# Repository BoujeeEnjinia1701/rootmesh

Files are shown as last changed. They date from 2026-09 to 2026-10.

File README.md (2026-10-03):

# RootMesh

     

**Area:** Agriculture · **TRL:** 3 of 9 (proof of concept on paper) · **Value-engineering target:** USD 300 (estimated cost USD 281.45) · **Difficulty:** 2 of 5

Solar-powered stakes that measure soil moisture, temperature and EC and report over LoRa to a single gateway and dashboard.

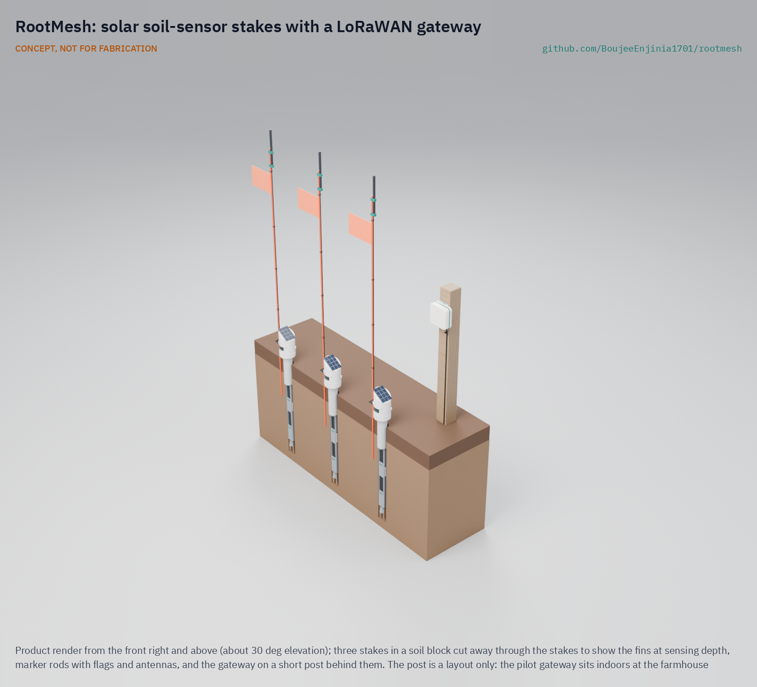
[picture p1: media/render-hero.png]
RootMesh: solar soil-sensor stakes with a LoRaWAN gateway, product render


*The gateway on a post in this render is a layout only; the pilot gateway is indoors.*

[Exploded render](media/render-exploded.png) · [Detail render](media/render-detail.png) · [Interactive 3D model](media/viewer.html) · [Concept blueprint (PDF)](media/concept-blueprint.pdf) · [General arrangement RMS-DWG-001 (PDF)](cad/drawings/RMS-DWG-001.pdf) · [Sizing calculations](docs/04-calcs/01-sizing.md) · [Prototype build plan](docs/05-build-plan.md) · [Design decisions](docs/06-design-decisions.md) · [Review note](docs/REVIEW.md)

## Concept rationale

Soil moisture only helps an irrigation decision if it is measured where the roots are, at more than one depth, and often enough to see the root zone drying between waterings. A buried stake with two capacitive probes, an EC pair and a temperature sensor answers that directly, and LoRaWAN lets one cheap gateway at the farmhouse collect a whole field without SIM cards or subscriptions. The stake sips about 2.6 mAh a day, so a palm-sized solar panel and a small LiFePO4 cell keep it running through a season with no battery changes.

RootMesh is open and garage-buildable because the growers who most need measured soil data are the ones least able to pay $150 to $600 a point for closed commercial nodes. Every part is a hobby-grade module, a hardware-store pipe or a printed piece, the known failure modes of cheap probes are designed out in the open, and a grower, extension office or school can build, repair and recalibrate the stakes without a vendor.

## Burning platform

In most regions of the world, more than 70 % of freshwater goes to agriculture ([World Bank, 2017](https://blogs.worldbank.org/en/opendata/chart-globally-70-freshwater-used-agriculture)), and irrigated land, about a fifth of cultivated area, grows about 40 % of the world's crops ([FAO, State of the World's Land and Water Resources, fast facts](https://www.fao.org/fileadmin/user_upload/newsroom/docs/en-solaw-facts_1.pdf)). Much of that water comes from aquifers that are falling: India, the largest groundwater user in the world, draws about 230 km³ a year, over a quarter of the global total, and more than 60 % of its irrigated agriculture depends on groundwater ([World Bank, 2012](https://www.worldbank.org/en/news/feature/2012/03/06/india-groundwater-critical-diminishing)).

Better timing is one of the cheapest levers. A systematic review of U.S. studies found that scheduling irrigation with soil water sensors used about 38 % less water than traditional scheduling, with similar or higher yields ([Datta and Taghvaeian 2023, *Agricultural Water Management*](https://www.sciencedirect.com/science/article/pii/S0378377423000136)). Yet field-ready wireless soil sensors still cost $150 to $600 or more per measurement point (see Problem below), which keeps them off most small farms.

## Where it could be used

### By industry

| Industry | Use |
| --- | --- |
| Vegetable and market gardening | Know when beds on drip or furrow irrigation are drying at 150 and 300 mm, and stop overwatering shallow-rooted crops |
| Orchards and vineyards | Track deep moisture and salinity through the season in a few representative blocks, and time deficit irrigation |
| Row and field crops | Place a few stakes per field or pivot to decide when to start an irrigation cycle |
| Agricultural extension and research | Deploy many low-cost points to map variation across soils and teach irrigation scheduling with real data |
| Urban and community gardens | Share one gateway across many plots and volunteers, with one dashboard for watering rotas |
| Parks, sports turf and landscaping | Skip scheduled watering when the root zone is still wet |

### By country or region

| Country or region | Why it matters there |
| --- | --- |
| India | The world's largest groundwater user; more than 60 % of irrigated agriculture depends on groundwater, and 29 % of assessed groundwater blocks were semi-critical, critical or overexploited in 2004 ([World Bank, 2012](https://www.worldbank.org/en/news/feature/2012/03/06/india-groundwater-critical-diminishing)) |
| Sub-Saharan Africa (for example Kenya) | Only about 4 % of land is irrigated, against 37 % in Asia ([IFPRI, 2010](https://www.ifpri.org/blog/irrigating-africa/)); new small-scale schemes need low-cost tools to make scarce water go further from the start |
| United States (High Plains) | Water levels in the High Plains aquifer fell by an area-weighted average of 16.5 ft (about 5.0 m) from predevelopment to 2019, a loss of about 286 million acre-feet of stored water ([USGS, 2023](https://pubs.usgs.gov/publication/sir20235143/full)) |
| Spain | Spain used about 16.7 billion m³ of irrigation water in 2010, about 42 % of the EU total ([European Parliamentary Research Service, 2019](https://www.europarl.europa.eu/RegData/etudes/BRIE/2019/644216/EPRS_BRI(2019)644216_EN.pdf)), and most of its freshwater abstraction goes to agriculture |
| Australia (Murray-Darling Basin) | The Basin accounted for 62 % of Australia's irrigation water use in 2020-21, about 4.9 million ML ([Australian Bureau of Statistics, 2022](https://www.abs.gov.au/statistics/industry/agriculture/water-use-australian-farms/latest-release)), where irrigators budget water against their entitlements |

## What sparked the idea

The idea traces back to the USDA's field guide *Estimating Soil Moisture by Feel and Appearance* (April 1998), which still underpins much irrigation scheduling advice. It asks growers to dig samples with a probe, auger or shovel in 1 ft increments down to the root depth at three or more sites per field, squeeze each one in the hand and match it to photographs, and says that with experience the method reaches about 5 % accuracy ([USDA NRCS](https://www.wcc.nrcs.usda.gov/ftpref/wntsc/waterMgt/irrigation/EstimatingSoilMoisture.pdf)). RootMesh keeps the same logic, several sites and more than one depth in the root zone, but leaves the probes in the ground and sends the readings to the farmhouse every 20 minutes, so the sampling happens without the walk and the guesswork.

## Problem

Irrigation decisions rely on guesswork without cheap, field-hardy soil sensing. Commercial wireless soil nodes cost about $150 to $600 or more per measurement point, and the cheap hobby probes corrode and drift when buried.

## Concept

Solar-powered stakes that measure soil moisture, temperature and EC and report over LoRa to a single gateway and dashboard. Each stake reads water content at 150 mm and 300 mm, bulk EC and soil temperature every 20 min, runs on a 0.5 W panel and a small LiFePO4 cell, carries its antenna at about 1 m on the flagged marker rod, and costs about $59.15 in parts. A pilot set of three stakes, an indoor US915 gateway and a steel slot tool that pre-cuts the fin path is $281.45 (indicative), USD 18.55 under the USD 300 value-engineering target.

The sizing note [RMS-CAL-001](docs/04-calcs/01-sizing.md) finds 8 of 14 requirements met on paper and 5 at risk: moisture accuracy, range through tall crops, head and cell temperature in bare hot soil, installation in firm dry soil and probe life. The parametric model is `cad/src/model.py` (STEP and STL in `cad/step` and `cad/stl`).

Full design precis: [docs/02-concept.md](docs/02-concept.md)

## Key components

- Two capacitive moisture probes (sealed, TLC555 conversion) in a printed sensor fin
- DS18B20 temperature probe
- Stainless EC electrodes with AC excitation
- LoRaWAN module (Seeed Wio-E5, STM32WLE5) with solar charger
- Sleeve dipole antenna at about 1 m on the marker rod
- 600 mAh LiFePO4 cell below grade
- 0.5 W PV panel on a printed ASA head over a PVC stake tube
- Indoor LoRaWAN gateway on The Things Network and an open-source dashboard
- Steel slot tool with a depth stop, one per set, to pre-cut the fin path before installation

The working bill of materials is in [bom/bom.csv](bom/bom.csv).

## Building the prototype

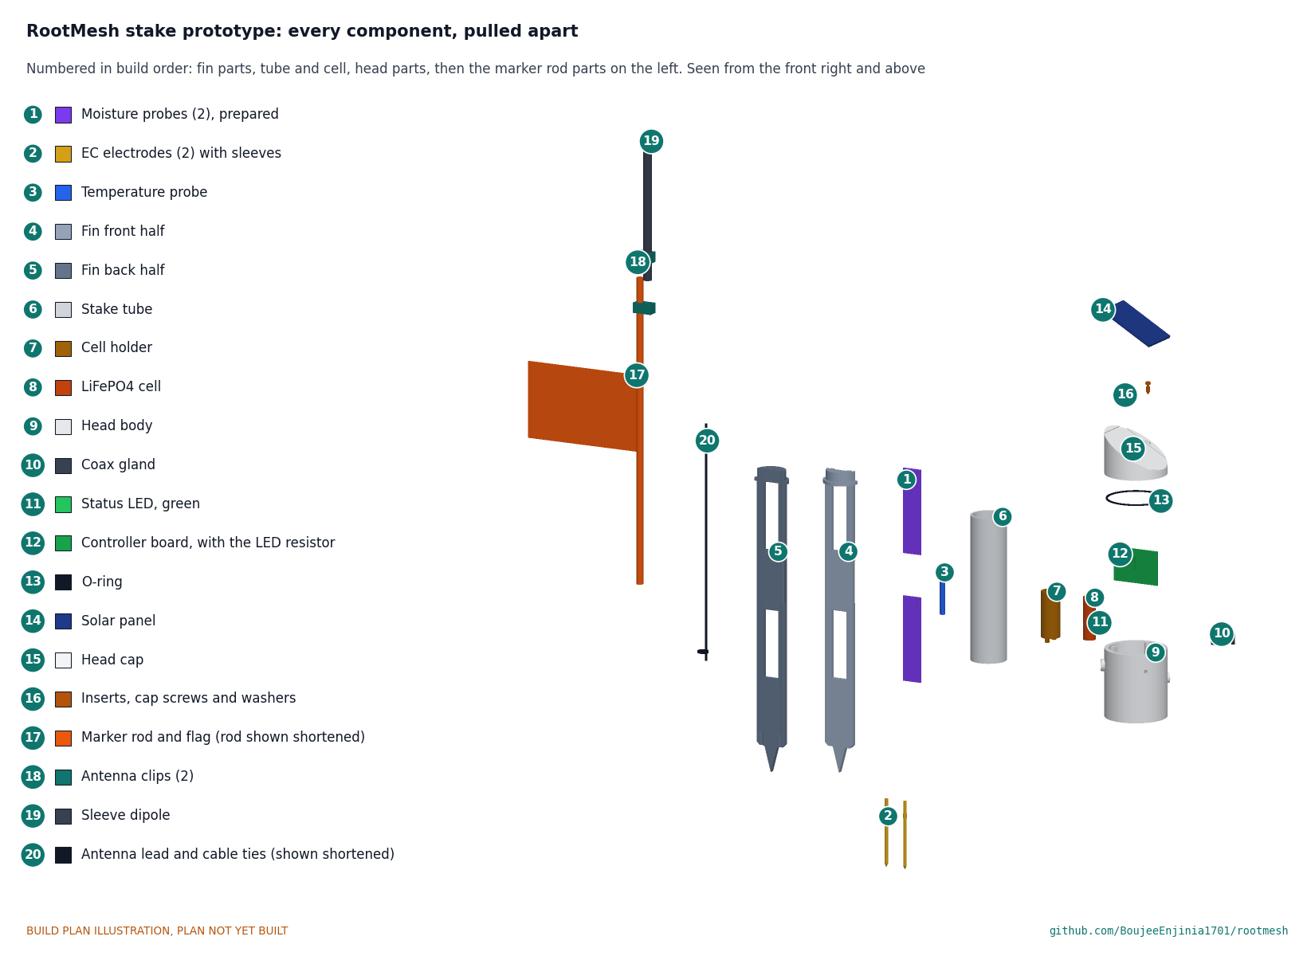
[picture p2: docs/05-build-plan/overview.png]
RootMesh stake prototype: every component pulled apart and numbered in build order


The [prototype build plan](docs/05-build-plan.md) (RMS-BLD-001) shows, in pictures, how to make each of the nineteen stake components and the slot tool and put them together in sixteen steps; nothing has been built yet. The made parts are a sensor fin printed in two glued halves, a printed head body and cap, a printed cell holder and antenna clips, a cut PVC tube, two stainless electrodes and a steel slot tool; the electronics are bought modules wired at block level. Writing the plan made the design buildable: the head now has a removable cap sealed by an O-ring so the board can go in, the fin has slots, pockets and wire channels for its sensors and a collar the tube sits on, and the cell, antenna and slot tool handle have real fixings (RMS-DDR-003, open for Amish's review). Every picture is drawn from the model, and the model checks that each part touches what it should and clears what it should not.

## Repository layout

| Folder | Contents |
| --- | --- |
| `docs/` | Problem, concept, requirements, calculations and design decisions |
| `cad/src/` | build123d Python source, the source of truth for all geometry |
| `cad/step/`, `cad/stl/` | Exported models for FreeCAD, other CAD tools and printing |
| `cad/drawings/` | 2D sketches and dimensioned drawings |
| `bom/` | Bill of materials |
| `electronics/` | KiCad schematics and PCB layouts |
| `firmware/` | Microcontroller code |
| `media/` | Renders, perspectives and photos |
| `build-log/` | Dated prototyping notes |

## Documentation

Controlled documents follow the portfolio [documentation standard](.kit/STANDARDS.md). Each carries a document ID (RMS-PRC-001 for the precis), a version and a revision history. Branded PDFs are built with `python .kit/render.py` and attached to GitHub Releases when a document is tagged, for example `RMS-PRC-001/v1.0`.

## Credits

Designed by Amish Chadha. See [CONTRIBUTORS.md](CONTRIBUTORS.md) for roles. To cite this design, use [CITATION.cff](CITATION.cff) (GitHub shows it as "Cite this repository").

AI assistance (Claude) was used to accelerate concept renders, prototype documentation and first-pass sizing calculations. Design direction and all decisions are Amish Chadha's, recorded in this repository's decision records (`docs/decisions/`).

## Licenses

- **Hardware** (CAD, drawings, BOM, electronics): [CERN-OHL-S v2](LICENSE)
- **Software** (firmware, scripts, notebooks): [MIT](LICENSE-SOFTWARE)

A project of the [Design Molecule](https://designmolecule.com) lab.

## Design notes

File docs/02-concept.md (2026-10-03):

---
doc_id: RMS-PRC-001
title: RootMesh design precis
project: RootMesh
doc_type: Design precis
version: "0.7"
status: Draft
date: '2026-10-02'
author: Amish Chadha
license: CERN-OHL-S-2.0
revisions:
- version: "0.1"
  date: '2026-09-24'
  author: Amish Chadha
  change: Initial scaffold
- version: "0.2"
  date: '2026-09-25'
  author: Amish Chadha
  change: Populate to TRL 2 (architecture, components, airtime, energy, link budget, cost, safety, media)
- version: "0.3"
  date: '2026-09-25'
  author: Amish Chadha
  change: Apply Amish's decisions (RMS-DDR-001); antenna on the marker rod; numbers checked against RMS-CAL-001; parametric model and drawing RMS-DWG-001
- version: "0.4"
  date: '2026-09-25'
  author: Amish Chadha
  change: Recommendations accepted by Amish (DDR-002)
- version: "0.5"
  date: '2026-10-01'
  author: Amish Chadha
  change: Constructable design (RMS-DDR-003) and build plan RMS-BLD-001; costs and installation figures updated; budget treated as a value-engineering target
- version: "0.6"
  date: '2026-10-02'
  author: Amish Chadha
  change: 'Decisions of 2026-10-02 (RMS-DEC-001): first users on US915 (Texas A&M AgriLife Extension as first candidate), R9 cell limit restated on condition, status light kept'
- version: "0.7"
  date: '2026-10-02'
  author: Amish Chadha
  change: "Follow-ups of 2026-10-02: US915 airtime and link budget, status LED, chosen cell and cost redone; open question on region closed"
---

# RootMesh design precis

RootMesh is a hand-installed soil sensor stake that measures volumetric water content at 150 mm and 300 mm, bulk EC and soil temperature, and reports every 20 min over LoRaWAN to one gateway at the farmhouse, from which an open dashboard shows root-zone depletion against a threshold the grower sets. The sizing note RMS-CAL-001 finds that a stake needs about 2.6 mAh a day including cell self-discharge, so a 0.5 W panel harvests about 58 times that need in the worst month and a 600 mAh LiFePO4 cell alone lasts about 186 days. With the antenna raised to about 1 m on the marker rod, the radio link has 13.5 dB of margin at 1 km. A stake costs $59.00 in parts, and a pilot set of three stakes, a gateway and a steel slot tool for installation costs $281.00. Value-engineering target: USD 300. Estimated cost of the constructable design: USD 281 (USD 19 under the target). Eight of fourteen requirements are met on paper; five are at risk: moisture accuracy (R1), range through tall crops (R5), head and cell temperature in bare, hot soil (R9), pushing the fin into firm dry soil (R10) and probe life (R14). The slot tool brings installation in moist soil within one person's strength (about 386 N); firm dry soil still needs about 1.2 kN. The design was made constructable on 2026-10-01 (RMS-DDR-003, open for Amish's review), and the prototype build plan [RMS-BLD-001](05-build-plan.md) shows how each part is made and fitted; decisions still open are in the design decisions register [RMS-DEC-001](06-design-decisions.md).

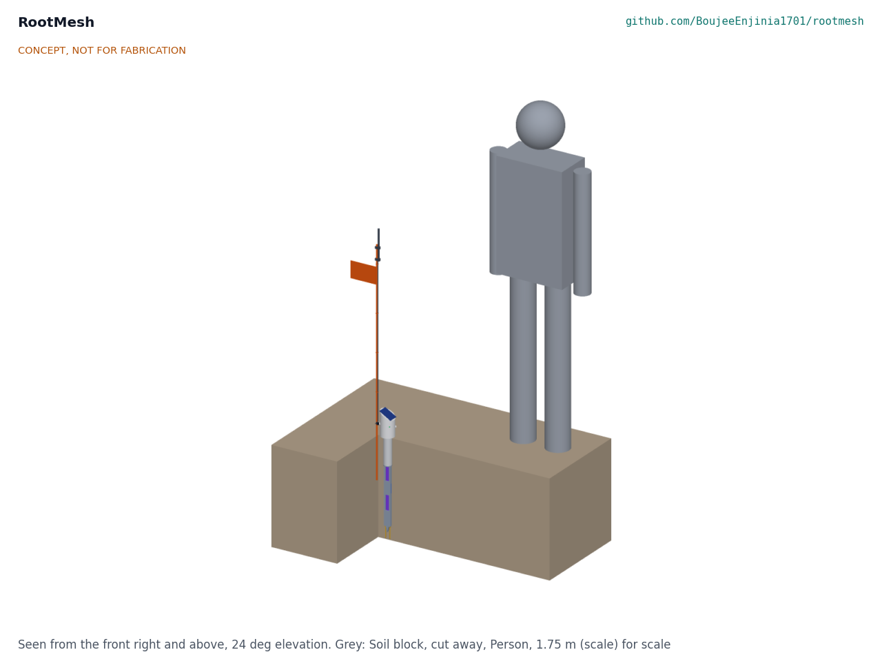
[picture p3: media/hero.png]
Hero render


*Figure 1. One RootMesh stake installed in soil, shown with the soil cut away, the marker rod with flag and antenna, and a 1.75 m person for scale.*

## How it works

1. **Sense.** Every 20 min the controller switches on the sensors for about 1 s. Two capacitive probes, held edge-on in windows of a printed fin, read water content at 150 mm and 300 mm. A DS18B20 on the fin edge reads soil temperature at about 225 mm. Two stainless electrodes below the fin tip read bulk EC with a short AC burst, so the electrodes do not polarize.
2. **Report.** The LoRaWAN module sends an 11 byte payload (24 bytes on air) at the slowest data rate the link needs, SF10 in the design case, through a sleeve dipole clipped to the top of the marker rod about 1 m above grade, then sleeps.
3. **Collect.** An indoor 8-channel gateway at the farmhouse forwards packets over Wi-Fi to The Things Network's free community server; a local server is a later option.
4. **Decide.** An open-source dashboard converts probe readings to water content with the site calibration, shows depletion between field capacity and the grower's refill point (the FAO-56 "management allowed depletion" idea; [Allen et al. 1998](https://www.fao.org/4/x0490e/x0490e00.htm)), and flags when the shallow or deep reading crosses it. Two depths show whether irrigation water has reached the lower root zone.
5. **Power.** A 0.5 W panel on the sloped head charges a 600 mAh LiFePO4 cell centered about 62 mm below grade, where the soil damps the daily temperature swing.

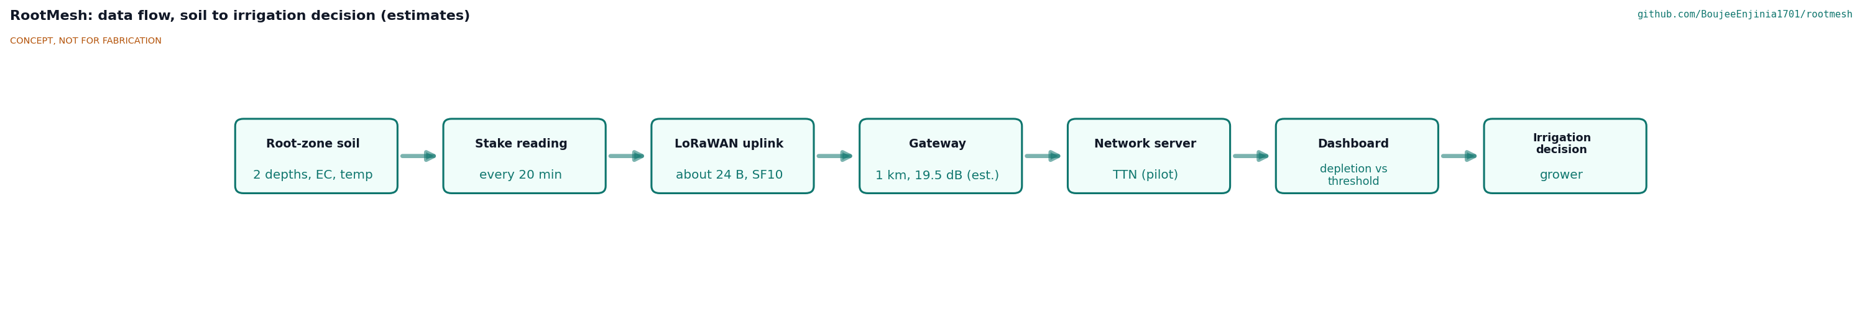
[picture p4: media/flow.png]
Data flow


*Figure 2. Data flow from the root zone to the irrigation decision. Interval, payload and range values are estimates.*

## Main components

Numbers match the exploded view (Figure 3) and `bom/bom.csv`.

| # | Component | Choice | Notes |
| --- | --- | --- | --- |
| 1 | Solar panel | 5 V, 0.5 W, about 70 x 50 mm, on a 30 degree slope | Self-cleaning slope sheds rain and dust |
| 2 | Head enclosure | Printed ASA body, 72 mm diameter, bonded over the tube, and a removable cap carrying the panel, sealed by an O-ring and two screws (RMS-DDR-003) | ASA for UV and heat; PETG softens near 70 °C |
| 3 | Controller board | STM32WLE5-class LoRaWAN module (for example Seeed Wio-E5, about $7; [Seeed Studio](https://www.seeedstudio.com/LoRa-E5-Wireless-Module-p-4745.html)) on a carrier with a LiFePO4 solar charger with NTC cut-off, a sensor power switch and the EC drive | One chip for radio and application; decided (RMS-DDR-001, D8) |
| 4 | Antenna and feed | Half-wave sleeve dipole clipped to the top of the marker rod, centered about 1,000 mm above grade, with a 1.2 m RG174 lead through a gland on the head | Decided (RMS-DDR-001, D2); a dipole because a whip on the rod has no ground plane |
| 5 | LiFePO4 cell | 14500, 3.2 V, 600 mAh (about 1.9 Wh), PTC fuse | Inside the tube below grade, in a printed holder standing on the fin spigot |
| 6 | Stake tube | 42 mm OD PVC pressure pipe, 170 mm | Carries the cable and the cell; bonded into the head and over the fin spigot |
| 7 | Sensor fin | Printed carrier 36 x 12 mm in section, 310 mm long, in two glued halves, two windows, wedge tip, collar and spigot at the top | Pushed into undisturbed soil below the 110 mm auger hole |
| 8 | Capacitive moisture probes (2) | v1.2-class boards with the NE555 replaced by a TLC555 and the edges sealed in epoxy, read as frequency | Fixes from the [Cave Pearl Project](https://thecavepearlproject.org/2020/10/27/hacking-a-capacitive-soil-moisture-sensor-for-frequency-output/) |
| 9 | EC electrodes | Two 316 stainless rods, 4 mm diameter, 24 mm apart | Two-electrode, AC excitation; cell constant set by calibration |
| 10 | Temperature probe | DS18B20 in a 6 mm stainless sheath, ±0.5 °C from -10 to 85 °C ([SparkFun](https://www.sparkfun.com/temperature-sensor-waterproof-ds18b20.html)) | Also compensates EC and moisture readings |
| 11 | Marker rod and flag | 1.2 m fiberglass rod, 8 mm, pushed 200 mm into the soil beside the stake | Visibility for machinery and people; carries the antenna |
| 12 | Seals and consumables | O-ring, IP68 glands, ePTFE vent membrane, desiccant, potting | The vent stops daily thermal pumping of about 15 kPa (RMS-CAL-001) |
| 13 | LoRaWAN gateway | Indoor 8-channel gateway with Wi-Fi (The Things Indoor Gateway class, about $79 to $90; [Seeed Studio](https://www.seeedstudio.com/The-Things-Indoor-Gateway-EU-p-4709.html)) | Not in the exploded view; The Things Network for the pilot decided (RMS-DDR-001, D3) |
| 14 | Dashboard | Open-source (for example Node-RED or Grafana) on an existing computer | Not in the exploded view |
| 15 | Slot tool | 32 x 8 mm mild steel flat bar, 650 mm, pointed, with a 20 mm bar handle through a cross hole and a printed 80 mm depth stop; one per set | Pre-cuts the fin and EC rod path; driven with a mallet, then withdrawn (RMS-DDR-002). Not in the exploded view |
| 16 | Head fixings and bonding | Two M3 heat-set inserts, two M3 cap screws with sealing washers, structural epoxy, heat-shrink sleeves, a 56 x 40 mm prototype board for the controller modules | Added for construction (RMS-DDR-003). Not in the exploded view |

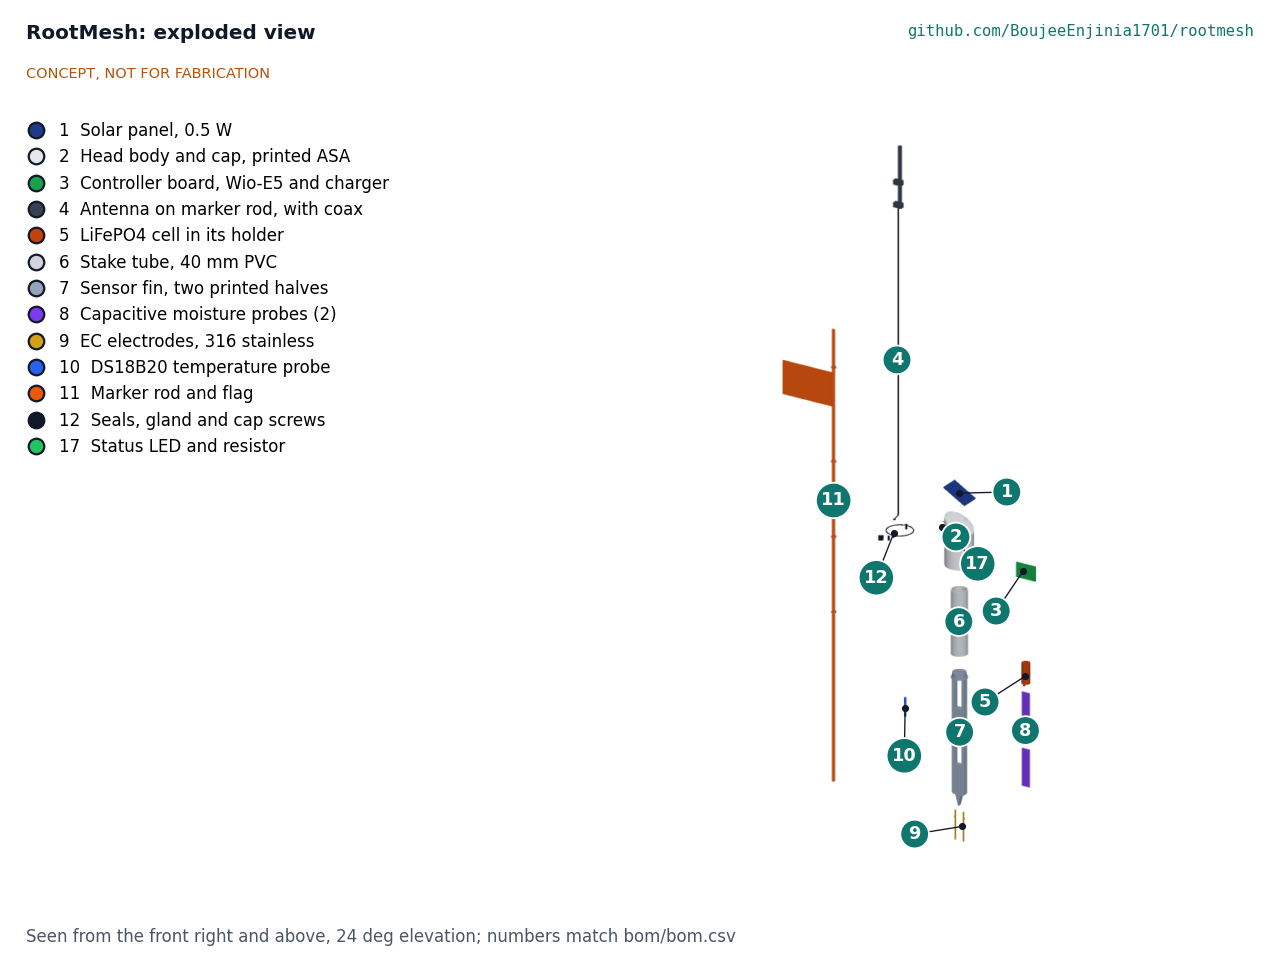
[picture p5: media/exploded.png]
Exploded view


*Figure 3. Exploded view of one stake with numbered callouts matching the BOM. The gateway and dashboard are not shown.*

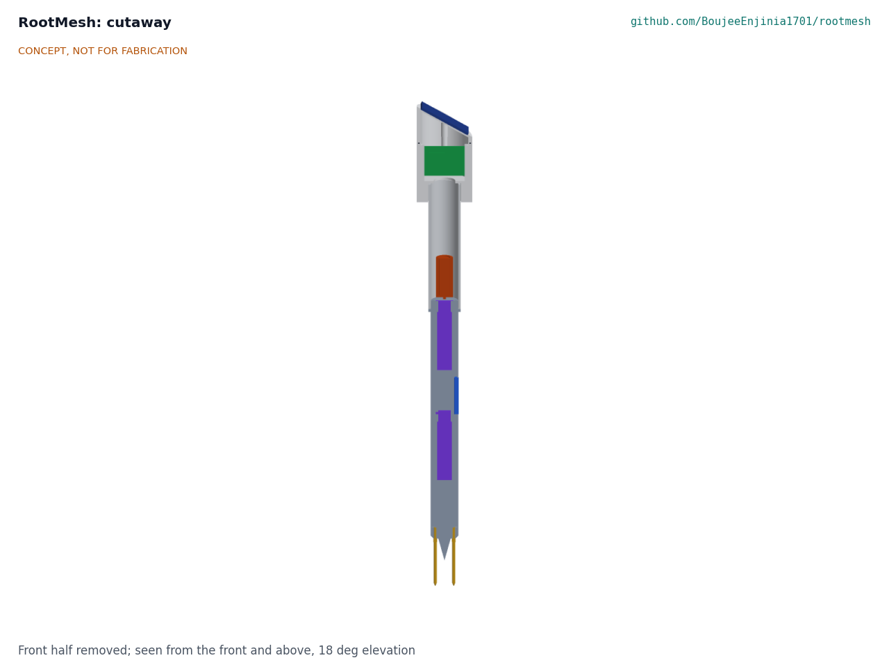
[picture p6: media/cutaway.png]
Cutaway


*Figure 4. Section through the stake: controller board in the head, cell in the tube below grade, moisture probes in the fin windows, temperature probe on the fin edge and EC electrodes below the tip. The marker rod and antenna are omitted for clarity.*

The general arrangement drawing [RMS-DWG-001](../cad/drawings/RMS-DWG-001.pdf) (Rev P2) gives the main dimensions and interfaces from the parametric model `cad/src/model.py`.

## First-order numbers

All values are estimates. They are checked in RMS-CAL-001, whose script `docs/04-calcs/sizing.py` prints every figure below.

### Airtime

Assumptions: 11 byte application payload plus 13 bytes of LoRaWAN overhead, 125 kHz bandwidth, coding rate 4/5, 8 symbol preamble, explicit header and CRC; time on air from the standard Semtech formula.

| Spreading factor | Time on air per uplink | Per day at 20 min (72 uplinks) | Per day at 15 min (96 uplinks) |
| --- | --- | --- | --- |
| SF7 | 62 ms | 4.4 s | 5.9 s |
| SF9 | 206 ms | 14.8 s | 19.8 s |
| **SF10 (design case)** | **371 ms** | **26.7 s** | **35.6 s, over the 30 s fair use limit** |
| SF12 (not allowed on US915) | 1.48 s | 106.8 s | 142.3 s |

At SF10 a 20 min interval fits The Things Network's 30 s per day fair use limit ([The Things Network](https://www.thethingsnetwork.org/docs/lorawan/duty-cycle/)); 15 min does not. With adaptive data rate, stakes close to the gateway will use SF7 to SF9 and could report every 10 to 15 min. On US915 there is no duty cycle, but each uplink may stay on a channel for at most 400 ms, so SF10 at 125 kHz (371 ms) is the slowest rate that can be used.

### Energy

Assumptions: sensors powered for 1 s at about 12 mA; microcontroller active 1.5 s at about 4 mA; transmit for the 0.371 s time on air at 120 mA (the Wio-E5 draws 111 mA at +22 dBm; [Seeed Studio](https://wiki.seeedstudio.com/LoRa-E5_STM32WLE5JC_Module/)); two receive windows 0.2 s at 6.7 mA; EC burst 20 ms at 10 mA; sleep 10 µA for the whole board including the charger; 30 % margin; cell self-discharge 3 % a month.

| Quantity | Value (RMS-CAL-001) | Basis | Requirement |
| --- | --- | --- | --- |
| Charge per report | 64.2 mAs | 12 + 6 + 44.5 + 1.3 + 0.2 + 0.2 (status LED) mAs | |
| Reports per day | 72 | Every 20 min | R4 |
| Load per day with margin | 1.98 mAh (6.3 mWh) | (1.29 active + 0.24 sleep) x 1.3 | |
| Self-discharge | 0.60 mAh per day | 3 % of 600 mAh a month | |
| **Daily need** | **2.58 mAh** | | |
| Days on the cell alone | 186 | 600 mAh x 80 % usable / 2.58 mAh | R6 (90 days) met |
| Harvest, 3 sun hours, open sky | 150 mAh per day, 58 times need | 100 mA panel current x 3 h x 50 % for tilt, dust, heat and linear charging | |
| Harvest, 1 sun hour | 50 mAh per day, 19 times need | | R6 met |
| Harvest under a canopy passing 10 % | 15 mAh per day, 5.8 times need | | |

The energy budget has large margin. That also means the panel is not strictly needed: a primary lithium cell would run a stake for years, which is how the Dragino LSE01 works ([Dragino](https://www.dragino.com/products/lora-lorawan-end-node/item/159-lse01.html)). Amish chose solar with a small rechargeable cell (RMS-DDR-001, D1) because it matches the pitch, avoids disposable cells and allows faster reporting. Charging stops below 0 °C, so in frozen ground a stake runs on its 186 days of reserve.

### Radio link

Assumptions: US915 at 915 MHz; stake radiates 20 dBm, with conducted power raised to 21.6 dBm (module maximum +22 dBm) to cover 1.6 dB of lead and connector loss; dipole taken at 0 dBi; gateway sensitivity -132 dBm at SF10 (typical SX12xx figure); 12 dB loss through the farmhouse wall and window; 10 dB allowance for crop foliage and fading; gateway at 3 m; two-ray ground reflection path loss, 40 log d - 20 log(h_t h_r), valid beyond about 115 m for these heights.

| Case | Path loss at 1 km | Loss budget available | Margin |
| --- | --- | --- | --- |
| Stake antenna 0.2 m, indoor gateway (TRL 2 layout) | 124.4 dB | 152 - 12 - 10 = 130 dB | 5.6 dB |
| **Stake antenna 1 m on the marker rod, indoor gateway (decided)** | **110.5 dB** | **130 dB** | **19.5 dB** |
| Stake antenna 0.2 m, outdoor gateway on a 6 m mast | 118.4 dB | 152 - 10 = 142 dB | 23.6 dB |

Raising the antenna to the top of the marker rod (RMS-DDR-001, D2) closes the link at 1 km on paper; at 0 dB margin it would reach about 3.1 km. The remaining risk is a crop taller than the antenna along the path: 50 m of maize or orchard can add about 13 dB and 100 m about 19 dB (Weissberger model), which leaves 0.1 dB at 100 m, so R5 stays at risk until a range walk.

### Measurement

- **Moisture.** Capacitance sensors respond to water, EC and temperature, more so at lower frequencies ([Kizito et al. 2008](https://www.sciencedirect.com/science/article/abs/pii/S0022169408000462)). Site-specific calibration cuts error to about one third of factory calibration ([Datta and Taghvaeian 2023](https://www.sciencedirect.com/science/article/pii/S0378377423000136)). The plan is a two-point field calibration (after irrigation to field capacity, and at a dry reading with a gravimetric sample) plus temperature correction from the DS18B20. Whether ±3 % VWC (R1) is reachable is unverified.
- **Air gaps.** A capacitive probe reads mostly the few millimeters of soil next to its surface, so any gap from installation reads as dry soil. The fin pushes into undisturbed soil below the auger hole to avoid this; contact quality is the largest measurement risk.
- **EC circuit.** Two 4 mm rods at 24 mm pitch with 60 mm exposed give a cell constant of about 0.13 cm⁻¹, so the electrodes read 1,315 Ω at 0.1 dS/m and 33 Ω at 4 dS/m against a 330 Ω reference. A 5 kHz square wave, sampled 10 µs after each edge, keeps polarization error under 1 %, and reading both sides of the reference resistor cancels the drive resistance (RMS-CAL-001, section D).
- **EC.** Bulk EC depends on moisture as well as salinity. Crop salinity thresholds in FAO-29 ([Ayers and Westcot 1985](https://www.fao.org/4/t0234e/t0234e00.htm)) use saturated-paste EC, so the dashboard should show EC as a trend and a pore-water estimate, not as a direct threshold. Readings are corrected to 25 °C at about 2 % per °C.

### Cost

| Group | Indicative cost | Requirement |
| --- | --- | --- |
| One stake (items 1 to 12, 16 and 17) | $59.15 | R12 ($60) met |
| Three stakes | $177.45 | |
| Gateway (item 13) | $90.00 | |
| Slot tool (item 15) | $14.00 | |
| **Pilot set** | **$281.45** | R12 ($300) met; USD 18.55 under the value-engineering target |
| Reference: Dragino SE01 node | about $151 to $170 per point ([Choovio](https://www.choovio.com/product/se01-lb-lorawan-soil-moisture-ec-sensor/)) | |

## Key design choices

Amish decided the choices below on 2026-09-25 by approving the TRL 2 recommendations (RMS-DDR-001). None is still "proposed".

- **Solar with a rechargeable LiFePO4 cell** (D1, D5): a 0.5 W panel and a 600 mAh LiFePO4 cell, rather than a primary Li-SOCl2 cell. Keeps the pitch and avoids disposable cells; adds a charger, a panel to keep clean and a cell that must not charge when frozen. LiFePO4 tolerates heat better than Li-ion and is less prone to thermal runaway.
- **Two moisture depths on one fin** (D6): 150 mm and 300 mm, to show whether water reached the lower root zone, at about $3 extra per stake.
- **Modified hobby capacitive probes** (D7): keeps the stake near $56; accuracy and life are the risks (R1, R14). A commercial reference sensor is to be borrowed for calibration later.
- **Wio-E5 (STM32WLE5) controller** (D8): one module for radio and application.
- **LoRaWAN on The Things Network for the pilot** (D3): free and simple; the fair use limit sets the 20 min interval at SF10, and a TTIG-class gateway works only with The Things Stack. A Raspberry Pi gateway with a local ChirpStack server stays a documented later option.
- **Indoor gateway, antenna on the marker rod** (D2): a sleeve dipole at about 1 m on the rod, fed by a 1.2 m lead, gives 19.5 dB margin at 1 km on US915 for $7 a stake. It adds a cable and a snag point; the rod is flexible and flagged.
- **Default interval 20 min** (D9): fits the fair use limit at SF10; faster with adaptive data rate near the gateway.
- **Budget read as a pilot set** (D4): the USD 300 value-engineering target covers three stakes and one gateway.
- **Steel slot tool for installation** (RMS-DDR-002): a pointed 32 x 8 mm steel blade, driven with a mallet down the auger hole and withdrawn, pre-cuts the fin path so the fin only widens the slot. Push force falls from 517 N to 376 N in moist loam and from 1,778 N to 1,216 N in firm dry loam (RMS-CAL-001 v0.2). Steel rather than a printed blade, because a printed blade would not survive firm soil.
- **Cell position kept at 62 mm** (RMS-DDR-002): a deeper cell was checked; in the constructable design the cell already sits as deep as fits above the fin spigot (62 mm, peak 46.8 °C in bare, hot soil), and meeting 40 °C would need about 163 mm, where the upper probe sits.

Decided by Amish on 2026-10-02 (RMS-DEC-001): the first users are a US university extension program with a research farm, on US915, with Texas A&M AgriLife Extension as the first candidate to approach; the cell limit of R9 is restated to the chosen cell's rated discharge range, provided its datasheet rates discharge to 55 °C or more, with charging still blocked above 45 °C, and otherwise a printed shade skirt is added; a green status light is kept on the head, blinking briefly after each uplink and on a magnet or button wake only, once its charge is in the energy budget. The link, airtime and power figures above are for US915 and include the status light (RMS-CAL-001 v0.5). The chosen cell is an IFR14500EC class cell, whose datasheet rates discharge from -20 to +60 °C, so no shade skirt is added.

## Safety

> **Safety:** Each stake holds a small lithium cell in a sealed enclosure buried in wet soil and exposed to sun, frost and machinery. The hazards are small but real.

- **Lithium cell.** A LiFePO4 cell of about 1.9 Wh is far less energetic than a phone battery, but a shorted or crushed cell can still overheat and vent. Fuse the cell (PTC), use a charger with an NTC input that blocks charging below 0 °C and above 45 °C, never charge a swollen or water-damaged cell, and do not leave stakes with cells in a closed hot vehicle. Plated lithium from charging below freezing can cause internal shorts later.
- **Sealed enclosure pressure.** A sealed head in sun warms from about 20 to 64 °C each day, a swing of about 15 kPa that would pump moisture past the seals. The head carries an ePTFE vent membrane and a desiccant.
- **Cell temperature.** In bare, hot soil the cell can reach about 47 °C (RMS-CAL-001). The charger's 45 °C cut-off stops charging, but check that the cell holder and fuse are rated for it, and never leave a stake in a closed vehicle.
- **Machinery and trips.** A stake struck by a tractor, mower or tiller can be thrown or can damage the implement; a low stake is a trip hazard. The flagged marker rod is part of the design, and stakes should be pulled before tillage. The antenna lead on the rod is a snag point; tape it to the rod.
- **Installation effort.** Pushing the fin into firm dry soil can take about 1.8 kN, or about 1.2 kN after the slot tool (RMS-CAL-001). Do not hammer on the head or stand on it; install after irrigation or pre-wet the hole, and cut the slot first.
- **Slot tool.** A pointed steel blade struck with a mallet: wear eye protection and gloves, keep feet clear of the point, keep the depth-stop collar fitted, and store the tool with a tip cover.
- **Sharp parts.** The fin tip and stainless electrodes are pointed; handle and store with tip covers, and keep away from children and livestock.
- **Chemicals and electrical.** Epoxy potting and conformal coating need gloves and ventilation. The stake runs at 3.2 V and carries no shock hazard; the gateway plugs into mains indoors through its own certified USB supply.
- **Data is not advice.** Readings inform a grower's decision. A failed or badly calibrated stake can read wet when the soil is dry, so growers should keep checking the crop, especially while the system is new.

## Open questions after TRL 3

- First users and region for co-design: decided on 2026-10-02, a US university extension program on US915, first candidate Texas A&M AgriLife Extension. The link budget and airtime for US915 are still to be worked.
- Can the moisture calibration reach ±3 % VWC in two soils (R1)? Needs a gravimetric calibration at TRL 4.
- Does the link hold through tall crops at 1 km (R5)? Needs a range walk at TRL 4.
- A deeper cell cannot keep the cell under 40 °C in bare, hot soil (R9). Decided on 2026-10-02: the cell limit is restated to the chosen cell's rated discharge range if its datasheet rates discharge to 55 °C or more; otherwise the soil around the head is shaded with a printed skirt.
- The slot tool brings moist soil within one person's strength on paper, but not firm dry soil (R10). A timed installation trial is TRL 4 work, on hold.
- Which edge seal lets the hobby probes last 12 months buried (R14)?

Concept media: [blueprint sheet](../media/concept-blueprint.pdf), [interactive 3D model](../media/viewer.html).

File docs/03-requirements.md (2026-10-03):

---
doc_id: RMS-REQ-001
title: RootMesh requirements
project: RootMesh
doc_type: Requirements
version: "0.7"
status: Draft
date: '2026-10-02'
author: Amish Chadha
license: CERN-OHL-S-2.0
revisions:
- version: "0.1"
  date: '2026-09-24'
  author: Amish Chadha
  change: Initial scaffold
- version: "0.2"
  date: '2026-09-25'
  author: Amish Chadha
  change: First measurable requirements for TRL 2, with concept status for each
- version: "0.3"
  date: '2026-09-25'
  author: Amish Chadha
  change: Apply Amish's decisions (RMS-DDR-001); redefine R4, R5, R11, R12 and R13; status from RMS-CAL-001
- version: "0.4"
  date: '2026-09-25'
  author: Amish Chadha
  change: Recommendations accepted by Amish (DDR-002)
- version: "0.5"
  date: '2026-10-01'
  author: Amish Chadha
  change: Figures for the constructable design (RMS-DDR-003, RMS-CAL-001 v0.3); budget treated as a value-engineering target; no status changed
- version: "0.6"
  date: '2026-10-02'
  author: Amish Chadha
  change: 'R9 cell limit restated to the chosen cell''s rated discharge range (55 °C or more), charging blocked above 45 °C, as decided by Amish on 2026-10-02'
- version: "0.7"
  date: '2026-10-02'
  author: Amish Chadha
  change: "Follow-ups of 2026-10-02: R5 margin on US915, R9 cell chosen, R12 cost with the status LED; no status changed"
---

# RootMesh requirements

These requirements reflect Amish's decisions of 2026-09-25 (RMS-DDR-001 and RMS-DDR-002) and the constructable design of RMS-DDR-003 and are checked by calculation in RMS-CAL-001. Targets are not yet validated with growers and will be revised after user input (see RMS-PRB-001; first users are still open). Nothing has been built or measured, so "met" means met on paper, by calculation or by a datasheet.

**Reference case:** one stake in a loam field, sensing at 150 and 300 mm, reporting every 20 min at SF10 to an indoor gateway about 1 km away, with the antenna at about 1 m on the marker rod, in a region with 3 peak sun hours per day in the worst month.

*Table 1. Requirements and TRL 3 status (RMS-CAL-001, Table 6).*

| ID | Requirement | Target | Verification (TRL 3 or later) | Status at TRL 3 |
| --- | --- | --- | --- | --- |
| R1 | Measure volumetric water content at two root-zone depths | 150 mm and 300 mm below grade (±25 mm); 5 to 50 % VWC; ±3 % VWC after a site-specific calibration | Model geometry; later gravimetric calibration in two soils | **At risk**: depths met by the model; accuracy depends on probe contact and calibration |
| R2 | Measure root-zone soil temperature | ±0.5 °C from -10 to 60 °C at about 225 mm depth | DS18B20 datasheet; model geometry | Met (datasheet; 225 mm in the model) |
| R3 | Measure bulk soil electrical conductivity | 0 to 4 dS/m; ±10 % or ±0.1 dS/m, whichever is larger, after calibration in standard solutions; reported at 25 °C | Circuit calculation; later bench test in KCl solutions and soil | Met on paper: circuit error under 2 % (RMS-CAL-001, D) |
| R4 | Report often enough for daily irrigation decisions | Every 20 min by default (RMS-DDR-001, D9); adjustable from 10 to 60 min where the spreading factor keeps uplink airtime at 30 s or less per day; the default fits at SF10 | Airtime calculation | Met: 26.7 s per day at SF10 and 20 min; 15 min needs SF9 or faster |
| R5 | Reach the gateway | 90 % or more of uplinks received at 1 km from an indoor gateway, with the stake antenna at about 1 m on the marker rod (RMS-DDR-001, D2), open field with a mature crop | Link budget; later field range walk | **At risk**: 19.5 dB margin at 1 km on US915 (20 dBm radiated), but a crop taller than the antenna can take 13 to 19 dB, which leaves 0.1 dB at 100 m of crop |
| R6 | Run on sun alone | Energy-neutral with 1 peak sun hour per day on the panel; 90 days or more of reporting with no harvest at all | Energy budget | Met: 19 times daily need at 1 sun hour; 186 days on the cell alone |
| R7 | Safe cell and charging | LiFePO4 chemistry, 2 Wh or less per stake; charging blocked below 0 °C and above 45 °C cell temperature; cell fused | Design review; charger datasheet | Met by design (1.92 Wh, NTC cut-off, PTC fuse) |
| R8 | Keep water out | Head IP67; buried section IP68 at 0.5 m for a growing season; UV-stable exposed parts | Design review; later immersion and spray test | Not verifiable at TRL 3; vent membrane added against 15 kPa daily thermal pumping |
| R9 | Operate across field temperatures | -10 to 60 °C at the head; at the cell, the chosen cell's rated discharge range, which its datasheet must rate to 55 °C or more, with charging blocked above 45 °C (restated from -5 to 40 °C by Amish, 2026-10-02; if the cell is not rated to 55 °C, a printed shade skirt round the head is added) | Component datasheets; thermal estimate | **At risk**: head about 64 °C and cell up to about 47 °C in bare, hot soil (parts rated 85 °C); inside the chosen IFR14500EC class cell's datasheet discharge range of -20 to +60 °C (RMS-DEC-001; no shade skirt needed); the head stays over its 60 °C |
| R10 | Install and remove by hand | One person with a 50 mm hand auger and the slot tool (RMS-DDR-002) installs a stake in 15 min or less, with sensing depths repeatable to ±25 mm; removal by hand in 5 min or less | Push-force estimate; later timed trial | **At risk**: with the slot tool about 386 N in moist loam (within one person's 500 N), about 1.2 kN in firm dry loam (without the tool 526 N and 1.8 kN); auger hole 110 mm deep (RMS-DDR-003) |
| R11 | Survive field operations | Rigid head 300 mm or less above grade; anything higher, including the antenna (RMS-DDR-001, D2), carried on the flexible marker rod; high-visibility marker 1 m or more above grade | Model check | Met: head 171 mm; rod top 1,000 mm; antenna 914 to 1,086 mm on the rod |
| R12 | Affordable | One stake $60 or less in parts; pilot set of three stakes, one gateway and the installation slot tool $300 or less, which is how the $300 value-engineering target is read (RMS-DDR-001, D4) | Priced BOM (`bom/bom.csv`) | Met: $59.15 per stake; $281.45 per pilot set including the slot tool, USD 18.55 under the value-engineering target (indicative, RMS-DDR-003 and the status LED of 2026-10-02) |
| R13 | Grower owns the data | Data readable without a paid subscription; CSV export; open dashboard. The pilot uses The Things Network community server (RMS-DDR-001, D3) | Design review | Met by design; a fully local server with a different gateway stays a later option |
| R14 | Last in the ground | Probes and electrodes last 2 growing seasons (about 12 months buried) without replacement | Materials review; later soak test | **At risk**: hobby probes corrode quickly unless sealed |

Summary: 8 met, 5 at risk (R1, R5, R9, R10, R14), 1 not verifiable at TRL 3 (R8), none not met.

## Assumptions

- Soil water content, not soil water potential, is the quantity measured. Converting it to plant-available water needs field capacity and wilting point for the soil, set during calibration (FAO-56 method).
- EC is measured as bulk soil EC. Pore-water or saturated-paste EC, which crop salinity thresholds use, differ and need a moisture-dependent conversion.
- LoRaWAN uplink payload of 11 bytes (two moisture counts, EC, temperature, cell voltage, status), 24 bytes on air with LoRaWAN overhead.
- SF10 at 125 kHz is the design case because it is the slowest uplink data rate allowed in the US915 plan and a reasonable margin case in EU868.
- The Things Network fair use policy (30 s of uplink airtime per node per day) applies when the community network is used.
- Worst-month solar resource of 3 peak sun hours on the panel before shading and dust losses.

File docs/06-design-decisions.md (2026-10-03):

---
doc_id: RMS-DEC-001
title: RootMesh design decisions register
project: RootMesh
doc_type: Design decisions register
version: "0.3"
status: Draft
date: '2026-10-02'
author: Amish Chadha
license: CERN-OHL-S-2.0
revisions:
  - version: "0.1"
    date: '2026-10-01'
    author: Amish Chadha
    change: Register opened with the open decisions from the review note and decision records, the design for construction (RMS-DDR-003), items to confirm when parts are bought, and the value-engineering summary
  - version: "0.2"
    date: '2026-10-02'
    author: Amish Chadha
    change: Amish approved the recommendations for open items 1 to 7 on 2026-10-02 (RMS-DDR-003 accepted, fin printed on a 300 mm class printer, head bonded, R9 cell limit restated on condition, Texas A&M AgriLife Extension on US915 as first candidate, status light, gateway indoors); moved to decisions made
  - version: "0.3"
    date: '2026-10-02'
    author: Amish Chadha
    change: "Follow-ups of 2026-10-02 carried out; cost restated with the status LED (line 17)"
---

# RootMesh design decisions register

Every design decision still to be made, and every decision made, in one place. Each decision is argued in full in its decision record under `docs/decisions/` or in the review note (`docs/REVIEW.md`); this register is the index Amish works from. The build plan (`docs/05-build-plan.md`) describes the design as it stands and does not list open decisions.

## Open decisions

None. All open decisions were decided on 2026-10-02.

## To confirm when parts are bought

| # | What to confirm | Why it matters | Source |
| --- | --- | --- | --- |
| 1 | The moisture probe boards are 23 mm wide and 98 to 100 mm long, with their parts on one face within 16 x 3 mm at the top end | The fin's slots and electronics pockets are sized for them | RMS-DDR-003, P4 |
| 2 | The temperature probe's sheath is 6 mm across and about 50 mm long, and its inner wires fit a 3.5 x 5 mm channel with the jacket stripped | The fin's bore and channel are sized for it | RMS-DDR-003, P5 |
| 3 | The 14500 cell with its fuse and leads fits a 15 mm bore, 51 mm deep | The cell holder is sized for it | RMS-DDR-003, P7 |
| 4 | The PVC pipe is 42 mm outside and 36 mm inside diameter | The head socket (43 mm) and fin spigot (35.4 mm) leave glue gaps of about 0.5 and 0.3 mm | RMS-DDR-003, P3 |
| 5 | A 64 x 2 mm O-ring, an M8 gland for 2 to 4 mm cable with its locknut, and short M3 heat-set inserts for a 4.6 mm hole are available | The cap groove, gland boss and insert bosses are sized for them | RMS-DDR-003, P1 and P8 |
| 6 | The solar panel is 70 x 50 mm or smaller, with its lead near the centre of its back | The cap recess is 71 x 51 mm with a lead hole at its centre | RMS-DDR-003, P1 |
| 7 | The charger's temperature window is 0 to 45 °C | R7 and safety stops S3 to S5 depend on it | RMS-CAL-001, B6 |
| 8 | The shaft collars fit 20 mm bar | The slot tool handle depends on them | RMS-DDR-003, P11 |

## Value engineering

Value-engineering target: USD 300. Estimated cost of the constructable design: USD 281.45 (USD 18.55 under the target), for the pilot set of three stakes, one gateway and one slot tool; USD 59.15 per stake against R12's USD 60. The target is a hypothetical control target, not a limit. Main cost drivers and savings worth trying:

- The largest lines are the gateway (USD 90, about a third of the set), the controller board (USD 15 a stake, USD 45 for three), the antenna and feed (USD 7 a stake) and the seals (USD 5 a stake).
- Making the design constructable added USD 3.50 a stake (the two-part head, the fin halves, and the inserts, screws, epoxy and prototype board of line 16) and USD 4 on the slot tool (shaft collars and thumb screw); the set rose from USD 266.50 to USD 281, and to USD 281.45 on 2026-10-02 with the status LED and resistor of line 17 (USD 0.15 a stake).
- Savings worth trying: one gateway serves a whole farm, so the per-stake cost falls quickly in larger sets; the controller board's price should fall once the carrier board is designed at TRL 4; one slot tool serves every stake on a farm; O-rings, glands and inserts are much cheaper bought by the hundred.

## Decisions made

| Date | Decision | Decided by | Record |
| --- | --- | --- | --- |
| 2026-09-25 | TRL 2 review items D1 to D9: solar with a LiFePO4 cell, antenna at 1 m on the marker rod, The Things Network with an indoor gateway, the budget read as a pilot set, LiFePO4 chemistry, two moisture depths, modified hobby probes, Wio-E5 controller, 20 min interval | Amish: "proceed with all of your recommendations across all batches. Make sure we don't proceed to TRL 4 on any of them." | RMS-DDR-001 |
| 2026-09-25 | Slot tool for firm soil; deeper cell checked and kept at 62 mm; pilot set includes the slot tool; field calibration note decided but on hold | Amish: "i accept all your recommendations, go with them across all repos." | RMS-DDR-002, A1 to A4 |
| 2026-09-30 | Build plan format approved for all repos; open decisions go in this register, not in the build plan; the design is made physically buildable as the pictures are drawn | Amish: "this is the correct build plan ... this is a good quality document format. Extend this across all the other repos"; "If you are realising that the design cannot be built as per concept - fix the design assumptions to match and be physically feasible as you draw the illustrations." | RMS-BLD-001, RMS-DDR-003 |
| 2026-10-01 | The budget is a value-engineering target, not a limit; `budget_usd` stays USD 300 | Amish: "the budgets are a hypothethical control target to ensure we are thinking along a value engineering lens. its ok to ensure wording reflects that the hypothesis budget was x - the real cost being accrued is y" | This register, Value engineering |
| 2026-10-02 | Design for construction accepted, P1 to P11, as recorded (two-part head with O-ring and screws, which also settles the separate solar cap of the 2026-09-26 review; board guides; fin in two glued halves with collar and spigot; flush temperature probe; wedge tip and one-piece electrodes; cell holder; gland and vent moved; antenna clips; slot tool handle and stop fixings) | Amish: "i approve your recommendations for all 555 open decisions." | RMS-DDR-003, P1 to P11 |
| 2026-10-02 | Fin print size: option (a), each 355 mm fin half is printed on a 300 mm class printer or through a print service | Amish: "i approve your recommendations for all 555 open decisions." | RMS-DDR-003, A1 |
| 2026-10-02 | Head joint: option (a) for the prototype, the head is bonded to the tube; revisited after the TRL 4 soak test | Amish: "i approve your recommendations for all 555 open decisions." | RMS-DDR-003, A2 |
| 2026-10-02 | Cell temperature in bare, hot soil: option (B), R9's cell limit restated to the chosen cell's rated discharge range, with charging still blocked above 45 °C, provided its datasheet rates discharge to 55 °C or more; if it does not, the printed shade skirt round the head (option A) is added | Amish: "i approve your recommendations for all 555 open decisions." | RMS-DDR-002, P1 |
| 2026-10-02 | First users and region: a US university extension program with a research farm, on US915; first candidate to approach Texas A&M AgriLife Extension | Amish: "i approve your recommendations for all 555 open decisions." | RMS-DDR-001, O1 |
| 2026-10-02 | Status light: keep a green LED on the head, blinking briefly after each uplink and on a magnet or button wake only, once its charge is added to the energy budget (RMS-CAL-001) | Amish: "i approve your recommendations for all 555 open decisions." | REVIEW.md, 2026-09-26, item 2 |
| 2026-10-02 | Gateway in the hero render: the pilot gateway stays indoors as decided; the post in the hero render is a layout only, and its caption says so | Amish: "i approve your recommendations for all 555 open decisions." | REVIEW.md, 2026-09-26, item 3 |

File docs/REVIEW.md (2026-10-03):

# Review note: RootMesh

## Session 2026-09-25: /populate to a strong TRL 2 (overnight batch run)

### What was done

- `docs/01-problem.md` (RMS-PRB-001 v0.2): problem with sourced facts (water use, sensor adoption, sensor prices, hobby probe failure modes, calibration error), users, operating environment, constraints, out of scope, prior work with links, open questions. No co-design checklist existed, so none was kept or added.
- `docs/03-requirements.md` (RMS-REQ-001 v0.2): 14 measurable requirements (R1 to R14) with targets, verification and concept status, plus assumptions.
- `docs/02-concept.md` (RMS-PRC-001 v0.2): how it works, 14 numbered components, airtime, energy, radio link budget, measurement notes, cost, design choices, safety, open questions.
- `cad/src/concept_media.py`: massing model of one stake (panel, ASA head, controller board, antenna, LiFePO4 cell, PVC tube, sensor fin, two probes, EC electrodes, temperature probe, marker rod, seals). Hero context: soil block cut away around the stake and a 1.75 m person standing on the soil.
- `media/`: hero, blueprint sheet (PNG, PDF, SVG), cutaway, exploded view with BOM callouts 1 to 12, data flow diagram, `model.glb` and `viewer.html`.
- `bom/bom.csv`: 14 lines for a pilot set (three stakes and one gateway), rows 1 to 12 numbered to match the exploded view; `bom/bom-notes.md` rewritten.
- `README.md`: hero image and links line added; problem, concept and key components updated to match.
- `docs/pdf/`: branded PDFs of the three controlled documents.
- `project.yaml` unchanged. The pitch and problem still match the numbers.

### Key results (estimates, to be checked at TRL 3)

| Quantity | Estimate | Requirement |
| --- | --- | --- |
| Time on air, 24 byte uplink at SF10 | about 0.37 s | |
| Airtime per day at 20 min, SF10 | about 27 s (30 s limit) | R4 met |
| Airtime per day at 15 min, SF10 | about 36 s | 15 min not possible at SF10 |
| Daily use with 30 % margin | about 2.0 mAh (6.4 mWh) | |
| Life on the 600 mAh cell alone | about 240 days | R6 met |
| Solar harvest to use ratio | about 70 times (open sky), about 7 times (dense canopy) | R6 met |
| Link margin at 1 km, indoor gateway, antenna 0.2 m | about 0 dB | **R5 not met** |
| Same with antenna at 1 m on marker rod | about 14 dB | R5 met on paper |
| Cost per stake | about $52 | R12 met |
| Pilot set (three stakes and gateway) | about $246 against $300 | R12 met |

Requirements not met or at risk:

- **R5 (range) not met** with the modeled design (whip on the head, indoor gateway): about 0 dB margin at 1 km.
- **R4 partly:** met at the 20 min default, but a 15 min interval at SF10 breaks The Things Network's 30 s per day limit.
- **R1 (moisture ±3 % VWC) at risk:** depends on soil contact and a site calibration, both unverified.
- **R14 (12 months buried) at risk:** hobby probes corrode unless sealed well.
- **R13 partly:** the TTIG-class gateway works only with The Things Stack, so fully local data needs a different gateway.
- R3, R8 and R10 are unverified.

### Proposed, awaiting Amish

1. **Power and pitch.** A: 0.5 W solar panel with a LiFePO4 cell (keeps the "solar-powered" pitch). B: primary Li-SOCl2 cell, no panel (simpler, multi-year life, changes the pitch). Recommendation: A.
2. **Range fix.** A: antenna on the marker rod at 1 m (about $4 a stake). B: outdoor gateway on a mast (about $150 to $250 more, over budget). C: accept about 500 m range. Recommendation: A. The model and BOM still show the whip on the head.
3. **Network.** The Things Network with a TTIG-class gateway for the pilot, or a Raspberry Pi gateway with local ChirpStack (about $60 to $100 more). Recommendation: TTN for the pilot.
4. **Budget reading.** The $300 taken as a pilot set of three stakes and one gateway. `budget_usd` unchanged.
5. LiFePO4 rather than Li-ion chemistry.
6. Two moisture depths (150 mm and 300 mm) rather than one.
7. Modified hobby capacitive probes rather than commercial FDR probes.
8. STM32WLE5-class module (Seeed Wio-E5) as the controller.
9. Default reporting interval of 20 min.
10. First users and region (market garden, orchard, research farm or extension program).

### Safety concerns

- LiFePO4 cell (about 1.9 Wh) in sun and frost: fused, charging blocked below 0 °C and above 45 °C, cell kept below grade.
- Machinery strikes and trip hazard: flagged marker rod; pull stakes before tillage.
- Pointed fin tip and electrodes: tip covers in storage.
- Epoxy and conformal coating: gloves and ventilation.
- Bad readings can mislead irrigation: the documents say readings inform, not replace, the grower's judgment.

### Problems and notes

- Several parts are small next to a 1.75 m person, so the hero shows a soil block cut away around the stake to make the buried sensors visible. The DS18B20 (10) and cell (5) are small in the exploded view but visible below their callouts.
- The LoRa module and carrier board are one BOM line (3) so the callout marks a visible part.
- Transmit current (about 120 mA) is an order-of-magnitude figure for an SX126x-class radio; confirm from the chosen module's datasheet at TRL 3.
- The link budget uses a simple two-ray model and typical sensitivity; range must be walked at TRL 4.
- The legacy `cad/src/model.py` placeholder is untouched (TRL 3 work).

### Suggestions (not done, outside this session's scope)

- A calibration note (CAL) for the two-point field calibration and EC cell constant at TRL 3.
- A simple printed tool to cut a slot for the fin in heavy soils.

### Recommended next step

Review this note and the media, then decide items 1 and 2. If approved, run `/advance-trl3` to check the energy, airtime, link and EC circuit numbers by calculation and produce the parametric model and drawing sheet.

## Session 2026-09-25: TRL 3

Amish approved all TRL 2 recommendations on 2026-09-25 ("proceed with all of your recommendations across all batches. Make sure we don't proceed to TRL 4 on any of them."). This session advanced RootMesh to TRL 3 and stopped there.

### What was done

- `docs/decisions/0001-trl2-review-decisions.md` (RMS-DDR-001 v0.1): the nine decided items (D1 to D9) and the one open item (O1).
- `docs/04-calcs/01-sizing.md` (RMS-CAL-001 v0.1) and `docs/04-calcs/sizing.py`: airtime, energy, radio link, EC circuit, sensing geometry, thermal and sealing, installation force and cost, with a results table for R1 to R14. The script imports the model's parameters, reads the BOM and `project.yaml`, and prints every number the note quotes.
- `cad/src/model.py`: parametric build123d model of one installed stake (head, panel, controller, tube, cell, fin, probes, EC rods, temperature probe, seals, marker rod, flag, antenna and lead). Exports `cad/step/` and `cad/stl/`: `rootmesh-stake-assembly`, `head-enclosure`, `sensor-fin`, `stake-tube`.
- `cad/src/sheets.py` and `cad/drawings/RMS-DWG-001.svg`, `.pdf`, `.png`: general arrangement at Rev P1, orthographic views at 1:5, installed elevation at 1:20, isometric, main dimensions and interfaces. The concept sheet keeps RMS-DWG-010, so RMS-DWG-001 was free. The sheet carries "CONCEPT, NOT FOR FABRICATION" and "PRELIMINARY, NOT FOR FABRICATION".
- `bom/bom.csv` and `bom/bom-notes.md`: every line priced with a supplier or supplier type; antenna and feed now $7.00 (on the marker rod), seals $5.00 (vent added). Pilot set $256.50 against $300.
- `cad/src/concept_media.py` now builds the media from `model.py`; all media refreshed (hero, blueprint, cutaway, exploded, flow, `model.glb`, `viewer.html`) and checked by eye. Temporary `media/_views*` folders removed.
- RMS-PRB-001, RMS-PRC-001 and RMS-REQ-001 revised to v0.3; `README.md` and `project.yaml` (trl 3, trl_target 3, evidence list) updated. Pitch, problem and `budget_usd` unchanged.
- Model fix found on the way: the TRL 2 massing model tilted the panel away from the equator; the parametric model faces it toward +X as the precis says.

### Requirements (RMS-CAL-001, Table 6)

Counts: 0 not met, 5 at risk, 1 not verifiable at TRL 3, 8 met.

| ID | Status | Key number |
| --- | --- | --- |
| R1 moisture | At risk | Depths 150 and 300 mm met by the model; ±3 % VWC unverifiable on paper |
| R5 range | At risk | 13.5 dB margin at 1 km with the antenna at 1 m; 50 to 100 m of tall crop takes 13 to 19 dB |
| R9 temperature | At risk | Head about 64 °C at 45 °C air (limit 60 °C; parts rated 85 °C); cell up to about 47 °C in bare hot soil (limit 40 °C) |
| R10 installation | At risk | Push force about 520 N in moist loam, about 1.8 kN in firm dry loam; one person gives about 500 N |
| R14 probe life | At risk | 12 months buried depends on the epoxy edge seal |
| R8 sealing | Not verifiable at TRL 3 | Sealed head would see about 15 kPa daily thermal pumping; ePTFE vent added |
| R2, R3, R4, R6, R7, R11, R12, R13 | Met | 26.7 s/day airtime at SF10; 2.58 mAh/day need, 186 days dark, 19 times need at 1 sun hour; 1.92 Wh cell; EC circuit error under 2 %; head 171 mm; $55.50 per stake |

Corrections to TRL 2 figures: days on the cell fell from about 240 to 186 (self-discharge), the harvest ratio from about 70 to 58 times, and the pilot set rose from about $246 to $256.50.

### Decisions recorded (RMS-DDR-001)

Decided by Amish, 2026-09-25: go with recommendation.

- D1 solar panel with rechargeable cell (pitch kept); D2 antenna on the marker rod at about 1 m; D3 The Things Network with a TTIG-class gateway for the pilot; D4 $300 read as a pilot set of three stakes and a gateway (`budget_usd` unchanged, written into R12); D5 LiFePO4; D6 two moisture depths; D7 modified hobby capacitive probes; D8 Wio-E5 (STM32WLE5); D9 20 min default interval.
- Requirement changes that follow: R4 redefined around the 20 min default, R5 for the antenna on the rod, R11 so that only the rigid head is held to 300 mm, R12 and R13 name the decisions. No target was relaxed.
- The portfolio SwapCell decisions do not apply; RootMesh uses no SwapCell pack.

### Still awaiting Amish

- O1: first users and region for co-design (market garden, orchard, research farm or extension program), which also sets EU868 or US915. No recommendation was made; co-design partners are to be picked per area later.

### Safety concerns

- LiFePO4 cell (1.92 Wh): may reach about 47 °C in bare, hot soil; the charger's 45 °C cut-off only stops charging. Fused (PTC), charging blocked below 0 °C.
- Sealed head: about 15 kPa daily pressure swing without a vent; ePTFE vent added.
- Machinery strikes and trips: flagged marker rod; the antenna lead on the rod is a snag point; pull stakes before tillage.
- Installation: up to about 1.8 kN in firm soil; do not hammer on or stand on the head.
- Pointed fin tip and electrodes; epoxy and coating fumes; readings inform, not replace, the grower's judgment.

### Citations and other notes

- The TRL 2 note listed no unchecked citations. The module currents that note flagged were checked against the Seeed Studio Wio-E5 module page (111 mA at +22 dBm, 6.7 mA receive, 2.1 µA sleep) and cited in RMS-CAL-001.
- No TRL 4 material exists in the repo (`electronics/` and `firmware/` are empty; `build-log/` holds only its README). None was created.

### Recommended next step

TRL 4 is on hold by Amish's instruction; this repo stops at TRL 3. Useful paper work that stays within TRL 3: decide O1 (first users and region), then consider design responses to the at-risk items, such as a deeper cell position or soil shade for R9 and a thin slot tool for R10, as a TRL 3 revision.

For the record only, TRL 4 would need: a lab test report (TST, `environment: lab`) covering the EC circuit in KCl standards, gravimetric moisture calibration in two soils, a soak and immersion test of the sealed head and probes, and a measured energy budget on a built stake; build log entries; and later a field range walk through tall crops. None of this is to start until Amish lifts the TRL cap.

## Session 2026-09-25: recommendations accepted

Amish wrote on 2026-09-25, in chat: "i accept all your recommendations, go with them across all repos." This session applied that instruction inside this repo only, at TRL 3, and recorded it in `docs/decisions/0002-recommendations-accepted.md` (RMS-DDR-002 v0.1).

### Decisions applied and what changed

The TRL 2 items D1 to D9 were already decided in RMS-DDR-001 and are unchanged. Newly decided (Decided by Amish, 2026-09-25: go with recommendation):

| # | Item | Change | Before | After |
| --- | --- | --- | --- | --- |
| A1 | Slot tool for firm soil (TRL 2 suggestion) | Steel slot tool, 32 x 8 mm blade pointed at 485 mm, T-handle, printed depth stop; `build_slot_tool()` in `cad/src/model.py`, `cad/step/slot-tool.step` and `cad/stl/slot-tool.stl`; BOM line 15 | Push force 517 N moist, 1,778 N firm dry | 376 N moist, 1,216 N firm dry |
| A2 | Deeper cell for R9 (TRL 3 recommended next step) | Checked by calculation (RMS-CAL-001 v0.2, [F4]); no geometry change | Cell peak 46.8 °C at 62 mm | Deepest fit about 65 mm gives 46.5 °C; 40 °C needs about 163 mm, where the upper probe sits; cell stays at 62 mm |
| A3 | Pilot set includes the slot tool | R12 restated; `budget_usd` unchanged at $300 | Pilot set $256.50, headroom $43.50 | $266.50, headroom $33.50 |
| A4 | Field calibration note (TRL 2 suggestion) | Decided but on hold: the field calibration needs gravimetric samples and KCl standards (TRL 4) | | |

Documents changed: RMS-PRC-001 v0.3 to v0.4, RMS-REQ-001 v0.3 to v0.4, RMS-CAL-001 v0.1 to v0.2 (script `docs/04-calcs/sizing.py` updated and re-run), RMS-DWG-001 Rev P1 to P2 (slot tool note), `bom/bom.csv` and `bom/bom-notes.md`, `README.md`, `project.yaml` (evidence list only). Media and all PDFs regenerated; STEP and STL re-exported. RMS-PRB-001 is unchanged (it did not attribute the idea to a brainstorm or review).

### Requirement status (RMS-CAL-001 v0.2)

Counts unchanged: 0 not met, 5 at risk, 1 not verifiable at TRL 3, 8 met.

- At risk: R1 (moisture accuracy), R5 (range through tall crops), R9 (head about 64 °C; cell about 47 °C in bare, hot soil), R10 (now 376 N in moist loam, within one person's 500 N, but 1,216 N in firm dry loam), R14 (probe life).
- Not verifiable at TRL 3: R8 (sealing).
- Met: R2, R3, R4, R6, R7, R11, R12 ($55.50 per stake, $266.50 pilot set), R13.

### Still awaiting Amish

- O1: first users and region for co-design (sets EU868 or US915). No recommendation was made.
- P1 (new, from the A2 check): respond to the cell temperature in bare, hot soil by (A) a printed shade skirt around the head or (B) restating the R9 cell limit to the chosen cell's rated discharge and storage range, with charging still blocked above 45 °C. Recommendation: B, after confirming the cell's rated range.

### Cross-repo actions

None. No RootMesh recommendation needs another repo to change.

### Other changes

- `README.md`: added "Concept rationale", "Burning platform", "Where it could be used" and "What sparked the idea" before "Problem", with cited figures (World Bank, FAO, USGS, ABS, European Parliamentary Research Service, IFPRI, Datta and Taghvaeian 2023). The inspiration point is the USDA NRCS guide *Estimating Soil Moisture by Feel and Appearance* (April 1998).
- All generated files regenerated so they carry designmolecule.com.

### Safety

The slot tool adds a pointed steel blade struck with a mallet: eye protection, gloves, feet clear of the point, collar fitted, tip cover in storage (RMS-PRC-001 v0.4, Safety). The earlier concerns (cell temperature, installation force, machinery strikes, sealed-head pressure) stand.

### TRL 4

TRL 4 remains on hold by Amish's instruction. No hardware, test, trial, PCB or firmware work was started. The field calibration (A4), a timed installation trial with the slot tool and any build of it wait for Amish to lift the cap.

## Session 2026-09-26: product appearance model and photoreal renders

Amish chose RootMesh for the first batch of product renders on 2026-09-26. This session added an appearance model for photoreal renders; the massing model, BOM, calculations and drawing are unchanged.

### What was done

- `cad/src/product_model.py` (new): `product_parts()` returns 85 parts (18 shell, 7 internal, 60 context) with colour, material class, BOM line, group and explode offset, plus `TITLE` and three `RENDER_VIEWS` (hero, exploded, detail). It imports `PARAMS` and `derived()` from `cad/src/model.py`, and every main dimension and interface (tube, socket, head radius and height, 30 degree slope, panel size, board and cell positions, fin, windows, sensing depths, EC pitch, temperature probe depth, marker rod, flag and antenna height) is taken from there. Appearance detail added:
  - head with filleted top and bottom edges, a grip-rib band, a dark nameplate with a teal line, a green status light behind a clear lens, a gland nut and dome on the coax boss and a white ePTFE vent disc;
  - a solar cap split from the head on a parting line parallel to the slope, carrying the panel (cell grid and busbars) and two cap screws;
  - controller board with the LoRaWAN module shield, charger IC and connectors; O-ring; LiFePO4 cell with terminals in its holder;
  - stake tube with eased ends; sensor fin with filleted edges, teal depth marks below each window, the capacitive probes with an epoxy edge seal, a stainless temperature sheath and stainless EC electrodes;
  - marker rod with a fabric flag, cable ties along the coax, and the sleeve dipole with its clip;
  - context: a two-layer soil block cut away on the plane through the stakes, two more stakes, and the gateway on a short timber post with bracket, status light and USB lead.
- `README.md`: the hero image is now `media/render-hero.png`, with a link to `media/render-exploded.png`. The render files are produced separately.
- Matplotlib self-check previews (not committed) were used to check that the hero, exploded and detail views read clearly.

### Where the appearance model differs from model.py

1. **Solar cap as a separate part.** `model.py` has a one-piece printed head. The appearance model splits a 10 mm cap off the top on a parting line and shows it exploded with the panel. Proposed, awaiting Amish. Options: (A) keep the one-piece head and read the line as cosmetic; (B) adopt a separate cap with the panel bonded to it, sealed to the head by a second O-ring. Recommendation: B, because the panel and board could then be serviced without pulling the stake; size the second seal in the next design step.
2. **Status light.** A green status LED behind a clear lens on the front of the head is not in the BOM or the energy budget. Proposed, awaiting Amish. Recommendation: keep it, driven as a brief blink after each uplink and on a magnet or button wake only, and add its charge to the RMS-CAL-001 energy budget before adopting it.
3. **Gateway outdoors on a post.** `model.py` and RMS-DDR-001 D3 keep the TTIG-class gateway indoors at the farmhouse; the hero shows it on a short timber post behind the stakes so one frame explains the system. Proposed, awaiting Amish. Recommendation: keep the pilot gateway indoors as decided and treat the post as a render layout only; the render note says so.
4. **Stake spacing.** The hero places three stakes 330 mm apart on one section plane. In the field they stand in different parts of a block or field. Render layout only; no change proposed.
5. **Colours.** The massing colours are replaced with product colours: white head and cap, light grey tube, mid-grey fin, black probes, stainless electrodes and temperature sheath, orange rod and flag. Appearance only; no change proposed.

### TRL

This is an appearance model only, for renders. It adds no tolerances, fabrication detail, PCB layout or test work. `trl` stays 3 and TRL 4 remains on hold.

## Session 2026-09-27: kit 1.5.0 and image quality

- Kit 1.5.0 synced: STANDARDS v1.5 (sections 12 to 15: product renders, storefront images and image quality, public release, authorship and signing), `.kit/cards.py`, `.kit/image_qc.py`, `.kit/release_gate.py`, issue templates, and the `/render-product` and `/release` commands. `CLAUDE.md` now matches `.kit/CLAUDE.md`.
- Every `media/render-*.png` recaptioned from its original render with the new layout: the title, concept label and repository sit in a band above the render and the view note in a band below it, each line wrapped to the image width, so no text overlaps other text or the render or runs off the image. `media/card.png` and `media/social-preview.png` regenerated with the same rules.
- `python .kit/image_qc.py` and `python .kit/release_gate.py` pass. trl stays 3.

## Session 2026-10-01: kit 1.7.0, design for construction and prototype build plan

Amish approved the build plan format on 2026-09-30 and asked for it across all repos, with open decisions kept in a separate register; on 2026-10-01 he asked that budgets be treated as value-engineering targets. This session applied both to RootMesh at TRL 3. Nothing was built or tested.

### What was done

- Kit 1.7.0 installed (`.kit/`, `.claude/commands/`); `CLAUDE.md` matches `.kit/CLAUDE.md`.
- `cad/src/model.py` rewritten as a constructable model: `build_components()` gives every part, `build_parts()` groups them by BOM line for the concept media, `slot_tool_components()` gives the slot tool, and `python cad/src/model.py --check` runs 331 constructability checks (no overlaps, every joint touches, board and cell holder pass their openings, cap screws clear the panel, gland nut clears the board, fin halves fit a 300 mm print bed). All pass. STEP and STL exported for the assembly and every made part (`cad/step`, `cad/stl`).
- `docs/decisions/0003-design-for-construction.md` (RMS-DDR-003 v0.1, Draft): the design changes below, made under Amish's 2026-09-30 instruction to make the design physically buildable; open for his review.
- `cad/src/build_plan_media.py` (new): overview, slot tool overview, ten making sketches RMS-DWG-101 to 110, a fin inside-face layout, eleven joint close-ups, sixteen assembly step pictures and a wiring diagram, all drawn from the model.
- `docs/05-build-plan.md` (RMS-BLD-001 v0.1) and `docs/06-design-decisions.md` (RMS-DEC-001 v0.1), new.
- `bom/bom.csv` and `bom/bom-notes.md`: lines 2, 4, 5, 7, 11, 12 and 15 updated; line 16 (head fixings and bonding) added.
- `docs/04-calcs/sizing.py` and RMS-CAL-001 v0.3, RMS-REQ-001 v0.5, RMS-PRC-001 v0.5: re-run and updated for the constructable design; budget wording changed to a value-engineering target.
- RMS-DWG-001 Rev P4; concept media (`media/hero.png`, `exploded.png`, `cutaway.png`, `flow.png`, `concept-blueprint.*`, `model.glb`, `viewer.html`) regenerated.
- `project.yaml`: `design_state: constructable`; RMS-DDR-003, the build plan, the register and the media script added to `trl_evidence`; `budget_usd` unchanged at 300.
- `README.md`: value-engineering line, build plan and register links, a "Building the prototype" section with the overview picture (placed before "Repository layout", since this README has no "Safety" section), updated costs.

### Design changes made for construction (RMS-DDR-003)

1. Head split into a printed body bonded over the tube and a removable cap carrying the panel, sealed by a 64 x 2 mm face O-ring and held by two M3 screws with sealing washers into heat-set inserts; body wall 5 mm (was 3 mm); the one-piece head could not take the board and its O-ring sealed nothing.
2. Board held in two printed guide slots.
3. Fin topped by a 42 mm collar and a 35.4 mm spigot bonded in the tube; the tube moved up 14 mm (still 170 mm long) so the upper probe stays centred at 150 mm; auger hole 110 mm deep (was 120 mm).
4. Fin printed in two glued halves with probe slots, electronics pockets, wire channels, a temperature probe bore and electrode grooves; windows 19 mm wide (was 28 mm).
5. Temperature probe recessed into the fin edge (0.4 mm proud; it stood 7 mm out and would have been torn off).
6. Round tip replaced by a wedge between the electrodes; each electrode one 80 mm rod (15 mm held, 5 mm sleeved, 60 mm bare, as before).
7. Printed cell holder standing on the spigot, cell centre still 62 mm deep.
8. Coax gland moved to 100 mm above grade, turned toward the front, clear of the board.
9. Vent moved to the back right, clear of the screw bosses.
10. Two printed antenna clips and four cable ties in place of an overlapping block and a free-hanging lead.
11. Slot tool handle through a cross hole with two shaft collars; depth stop clamped by an M5 thumb screw; blade 650 mm as the BOM says.

### Key results

- Requirement status unchanged: 8 met, 5 at risk (R1, R5, R9, R10, R14), 1 not verifiable at TRL 3 (R8), none not met.
- R10: with the slot tool 386 N in moist loam (was 376 N) and 1,245 N in firm dry loam (was 1,216 N); the fin now starts 10 mm deeper.
- R9: the deepest cell centre that fits is now 62 mm (46.8 °C), where the cell already sits.
- Cost: USD 59.00 a stake (R12's USD 60 met by USD 1); pilot set USD 281.00. Value-engineering target: USD 300. Estimated cost of the constructable design: USD 281 (USD 19 under the target).

### Proposed, awaiting Amish

All open decisions are in `docs/06-design-decisions.md`: accept RMS-DDR-003; fin print size (A1); head bonded to the tube (A2); the R9 response (P1); first users and region (O1); the status light; the gateway in the hero render.

### Stale images

The design changed visibly (two-part head with a parting line and screw heads, collar on the fin, narrower windows, wedge tip, antenna clips). `media/render-hero.png`, `render-exploded.png`, `render-detail.png`, `media/card.png`, `media/social-preview.png` and the appearance model `cad/src/product_model.py` still show the concept and need regenerating on Amish's Mac.

### Safety

The build plan carries eight safety stops (cell, charging, slot tool, radio, field). The slot tool is a pointed steel blade struck with a mallet; grinding steel and epoxy work are added workshop hazards. The safety case is otherwise unchanged.

### Recommended next step

Review RMS-DDR-003 and the register. TRL 4 (building to this plan) stays on hold until Amish lifts the cap.

## Session 2026-10-02: open decisions decided

Amish, 2026-10-02: "i approve your recommendations for all 555 open decisions." This approves the recommendation written for each open decision in the design decisions register (RMS-DEC-001 v0.1). trl stays 3; no build or test work was done, and the model, BOM quantities and prices, and pictures are unchanged.

### Decisions recorded

Seven decisions, all moved to Decisions made in RMS-DEC-001, dated 2026-10-02:

1. RMS-DDR-003 accepted: design for construction P1 to P11, as recorded (including the separate solar cap).
2. Fin print size: option (a), a 300 mm class printer or a print service.
3. Head joint: option (a), bonded to the tube for the prototype; revisited after the TRL 4 soak test.
4. Cell temperature (R9): option (B), the cell limit restated to the chosen cell's rated discharge range, with charging still blocked above 45 °C, provided its datasheet rates discharge to 55 °C or more; otherwise the printed shade skirt (A) is added.
5. First users and region: a US university extension program with a research farm, on US915; Texas A&M AgriLife Extension is the first candidate to approach.
6. Status light: a green LED on the head, blinking briefly after each uplink and on a magnet or button wake only, once its charge is in the energy budget.
7. Gateway: indoors as decided; the post in the hero render is a layout only, and its caption says so.

### Documents changed

- `docs/06-design-decisions.md` (RMS-DEC-001 v0.2): open decisions moved to Decisions made; the note on the separate solar cap folded into decision 1.
- `docs/decisions/0003-design-for-construction.md` (RMS-DDR-003 v0.2, status Draft): accepted, with A1 and A2 accepted as recommended.
- `docs/decisions/0001-trl2-review-decisions.md` (RMS-DDR-001 v0.2): O1 recorded as decided.
- `docs/decisions/0002-recommendations-accepted.md` (RMS-DDR-002 v0.2): O1 and P1 recorded as decided.
- `docs/03-requirements.md` (RMS-REQ-001 v0.6): R9 cell limit restated (still at risk for the head).
- `docs/04-calcs/01-sizing.md` (RMS-CAL-001 v0.4): R9 target in the requirement table; no number re-run.
- `docs/02-concept.md` (RMS-PRC-001 v0.6): decisions on first users, US915, R9 and the status light; open questions answered.
- `docs/01-problem.md` (RMS-PRB-001 v0.4): first users and region.
- `README.md`: caption under the hero render (the post is a layout only).

### Follow-up actions to carry approved decisions into the design

1. Decision 4 (calculations and BOM): choose the cell, confirm from its datasheet that discharge is rated to 55 °C or more, and record it in the BOM notes; if it is not, add the printed shade skirt to the model, BOM, drawings and build plan pictures.
2. Decision 5 (calculations): redo the link budget, airtime and fair use figures of RMS-CAL-001 and RMS-PRC-001 for US915 (915 MHz, US power limits, 400 ms dwell time).
3. Decision 5 (model and BOM): cut the sleeve dipole for 915 MHz and specify the US915 gateway and antenna in the BOM (build plan section 3.12 and safety stop S7).
4. Decision 6 (calculations, model, BOM): add the LED's charge to the energy budget in RMS-CAL-001, then add the lens hole in the head body, the LED and its resistor to the model and BOM.
5. Decision 7 (pictures): put the "layout only" note in the hero render's own caption when the renders are next made (`.kit/photo_caption.py`).
6. Decision 1 (pictures): update `cad/src/product_model.py` to the constructable head, fin and antenna clip and re-render the photoreal renders, card and social preview on Amish's Mac.

### Points found in the review

- R9 also sets 60 °C at the head, which the head exceeds (about 64 °C at 45 °C air); neither option in decision 4 addresses it, and it was not an open item. R9 stays at risk for the head.
- Charging is blocked above 45 °C cell temperature, which in bare hot soil falls in the sunniest afternoon hours; the energy budget should show the solar charge still covers the load.

## Session 2026-10-02: approved follow-ups carried out

Amish, 2026-10-02: every follow-up action from the open-decision sign-off is approved and to be completed. trl stays 3; no build or test work was done. `budget_usd` is unchanged.

### Approved follow-ups carried out

1. Decision 4, cell: done. The cell is an IFR14500EC class LiFePO4 cell (600 mAh, 3.2 V). Its datasheet ([Simpower IFR14500EC](https://www.simpower.co.nz/wp-content/uploads/2021/11/IFR14500EC.pdf)) rates discharge from -20 to +60 °C and charge from 0 to +60 °C, so the 55 °C condition is met and the printed shade skirt is not added. BOM line 5 and the build plan record it; the charger still blocks charging above 45 °C. The datasheet is for the class, not for a purchased lot: check the supplier's own sheet before buying.
2. Decision 5, US915 calculations: done. RMS-CAL-001 v0.5 and RMS-PRC-001 v0.7 redo airtime (400 ms dwell limit, SF10 takes 371 ms), the link budget (915 MHz, 20 dBm radiated, margin at 1 km 19.5 dB) and the energy budget.
3. Decision 5, dipole and gateway: done. The model's dipole is 164 mm (was 172 mm); BOM line 4 is a 915 MHz dipole and line 13 the US915 gateway; build plan section 3.12 and stop S7 say so.
4. Decision 6, status LED: done. Charge added to the energy budget (RMS-CAL-001 [B1b]: 2.14 mA, 0.21 mAs per report, 3.2 mAs a day of wake blinks, five wakes a day assumed), then a 5.2 mm lens hole, the LED and its 560 Ω resistor added to the model (388 checks pass, 0 failures), BOM line 17 ($0.15 a stake), the build plan and the wiring picture.
5. Decision 7, hero caption: done in the render scene. The hero view's note now says the post is a layout only and the pilot gateway sits indoors; it travels in `rootmesh__jobs.json` to `.kit/photo_caption.py`.
6. Decision 1, appearance model and renders: the appearance model `cad/src/product_model.py` is updated to the constructable head (lens hole, gland and vent at the model positions), the fin collar and spigot, the cell holder, the two antenna clips, the cable tie heights and the 915 MHz dipole, with the dimensions read from `cad/src/model.py`. Render scenes exported to `/home/claude/renders/rootmesh` (hero, exploded, detail). Not done: the photoreal renders, `media/card.png` and `media/social-preview.png`, which are made on Amish's Mac next.

### Results

- Model: 388 constructability checks, 0 failures; STEP and STL regenerated.
- BOM: line 17 added; lines 3, 4, 5 and 13 reworded for US915 and the chosen cell; no other line changed. One stake $59.15, pilot set $281.45. Value-engineering target: USD 300. Estimated cost of the constructable design: USD 281.45 (USD 18.55 under the target). Mass is not tracked in the bill of materials.
- Requirement status changes: none (8 met, 5 at risk: R1, R5, R9, R10, R14; 1 not verifiable at TRL 3: R8). R5 margin rose to 19.5 dB but tall crops still take it down to 0.1 dB at 100 m of crop, so it stays at risk. R9 stays at risk because the head reaches about 64 °C against its 60 °C limit.
- Pictures regenerated: RMS-DWG-001 Rev P5, RMS-DWG-106 Rev P2 (lens hole), the other making sketches, concept media (hero, exploded, cutaway, blueprint, viewer), overview, joints 1 to 11, steps 1 to 16, wiring. `drawing.py --check-text` reports nothing.

### Documents changed

RMS-BLD-001 v0.2, RMS-CAL-001 v0.5, RMS-REQ-001 v0.7, RMS-PRC-001 v0.7, RMS-DEC-001 v0.3, with `README.md`, `bom/bom.csv`, `bom/bom-notes.md`, `cad/src/model.py`, `cad/src/product_model.py`, `cad/src/sheets.py`, `cad/src/build_plan_media.py`, `cad/src/concept_media.py` and `docs/04-calcs/sizing.py`. PDFs regenerated.

### Points found

- The 20 dBm radiated power is the module's practical limit (+22 dBm conducted less 1.6 dB of coax), not a regulatory figure; the US915 rules allow more. Proposed, awaiting Amish: none needed, but the energy budget already assumed the 22 dBm transmit current.
- The LED position (front right, 60 mm up) and the five wakes a day are my choices; both are easy to move.

### Cross-repo actions

- None for this repository's own follow-ups. Outreach to Texas A&M AgriLife Extension (decision 5) is Amish's and nothing is agreed.

## 2026-10-02: photoreal renders redone on the constructable design

Rendered with Blender Cycles on Amish's Mac from the updated appearance model; captioned with `.kit/photo_caption.py`; `media/card.png` and `media/social-preview.png` regenerated with `.kit/cards.py`. Views: hero, exploded, detail. image_qc passes. Appearance deviations are those logged above as proposed, awaiting Amish.

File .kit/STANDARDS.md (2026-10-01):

---
doc_id: OHP-STD-001
title: Documentation and drawing standard
project: Open Hardware Portfolio
doc_type: Standard
version: "1.7"
status: Released
date: 2026-09-30
author: Amish Chadha
license: CC-BY-SA-4.0
revisions:
  - version: "1.0"
    date: 2026-09-24
    author: Amish Chadha
    change: First release of the standard
  - version: "1.1"
    date: 2026-09-24
    author: Amish Chadha
    change: Adopt Technology Readiness Levels (section 9) for project maturity
  - version: "1.2"
    date: 2026-09-24
    author: Amish Chadha
    change: Portfolio phase cap (section 10), concept media standard (section 11), CLAUDE.md guardrails
  - version: "1.3"
    date: 2026-09-24
    author: Amish Chadha
    change: Scale figure, interactive 3D viewer and flow diagrams added to concept media; session slash commands
  - version: "1.4"
    date: 2026-09-26
    author: Amish Chadha
    change: Every sheet and render names the project and its GitHub repository; overall dimensions, ISO centre lines and 300 dpi PNG on sheets; titles name the device and view labels state the viewing direction; optional photoreal renders with Blender
  - version: "1.5"
    date: 2026-09-27
    author: Amish Chadha
    change: Product renders (section 12), storefront images and image quality check (section 13), public release and release gate (section 14), authorship, citation and commit signing (section 15)
  - version: "1.6"
    date: 2026-09-29
    author: Amish Chadha
    change: Licensing metadata with REUSE (section 16), Zenodo DOI and Software Heritage archiving (section 17), release gate checks REUSE and a single CITATION.cff license, archive.py
  - version: "1.7"
    date: 2026-09-30
    author: Amish Chadha
    change: Concept and constructable design states; design decisions register (DEC) kept apart from the build plan; prototype build plan (BLD, section 18) with pictures by component is required TRL 3 evidence; every repo targets TRL 3 during the populate phase; build_views.py; /to-trl3 and /build-plan commands
---

# Documentation and drawing standard

Every project in the portfolio uses this standard, so that each precis, write-up and sketch looks the same and carries its own version history. The standard ships as a kit in each repo's `.kit/` folder. The kit version is in `.kit/KIT_VERSION`.

## 1. Document types and IDs

Every controlled document has a unique ID in the form `PRJ-TYP-NNN`.

- `PRJ` is the three-letter project code listed in section 7.
- `TYP` is the document type code from the table below.
- `NNN` is a sequence number within that project and type, starting at 001.

| Code | Type | Typical file |
| --- | --- | --- |
| PRC | Design precis | `docs/02-concept.md` |
| PRB | Problem statement | `docs/01-problem.md` |
| REQ | Requirements | `docs/03-requirements.md` |
| CAL | Calculation or sizing note | `docs/04-calcs/*.md` |
| DDR | Design decision record | `docs/decisions/*.md` |
| BOM | Bill of materials | `bom/bom.csv` |
| DWG | Drawing or sketch sheet | `cad/drawings/*.svg` |
| BLD | Prototype build plan (section 18) | `docs/05-build-plan.md` |
| DEC | Design decisions register (section 18) | `docs/06-design-decisions.md` |
| TST | Test plan or test report (front matter adds `environment: lab` or `relevant`) | `docs/05-tests/*.md` |

Example: `TBK-PRC-001` is the ThermaBrick design precis.

## 2. Revision scheme

| Artifact | While in draft | When released | Change after release |
| --- | --- | --- | --- |
| Documents | 0.1, 0.2, 0.3 ... | 1.0 | 1.1 for minor edits, 2.0 for a design change |
| Drawings | Rev P1, P2 ... (preliminary) | Rev A | Rev B, C ... |

- Every change to a controlled document adds a row to its revision history before the commit.
- The `version` field in front matter always equals the newest row in `revisions`. The renderer rejects a document where they differ.
- Status is one of `Draft`, `In review`, `Released` or `Superseded`. Draft and In review documents print with a status band on every page.
- Every release is tagged in Git as `<doc_id>/v<version>`, for example `TBK-PRC-001/v1.0`. Drawings are tagged `TBK-DWG-001/revA`.
- Git history is the full audit trail. The in-document revision table is the human-readable summary.

## 3. Document front matter

Every Markdown document under version control starts with this block:

```yaml
---
doc_id: TBK-PRC-001
title: ThermaBrick design precis
project: ThermaBrick
doc_type: Precis
version: "0.1"
status: Draft
date: 2026-09-24
author: Amish Chadha
license: CERN-OHL-S-2.0
revisions:
  - version: "0.1"
    date: 2026-09-24
    author: Amish Chadha
    change: Initial draft
---
```

Quote version numbers so YAML keeps `1.0` as text instead of turning it into a number. List revisions newest last.

## 4. Writing style

- Chicago Manual of Style.
- No em dashes. Restructure the sentence instead.
- Lead each section with its conclusion, then support it.
- SI units throughout, in the form `12 kW`, `450 °C`, `3.2 m`. Imperial values may follow in parentheses.
- Number every figure and table ("Figure 2", "Table 1") and give each a caption.
- State every assumption in the calculation that depends on it.
- Put safety notes in a blockquote starting with **Safety:**.

## 5. Visual identity

| Element | Specification |
| --- | --- |
| Typeface | IBM Plex Sans for text, IBM Plex Mono for code and values (SIL Open Font License, bundled in `.kit/fonts`) |
| Ink | `#111827` |
| Secondary text | `#4B5563` |
| Rules and grid | `#D1D5DB` |
| Accent (one only) | `#0F766E` teal |
| Document page | US Letter, 20 mm margins |
| Drawing sheet | ANSI B landscape (431.8 x 279.4 mm) |
| Footer | Document ID, version, status, license and designmolecule.com on every page |

## 6. Drawing and sketch conventions

- Units are millimeters unless the title block says otherwise.
- Third-angle projection, marked with the symbol in the title block.
- Line weights: visible outlines 0.5 mm, hidden lines 0.25 mm dashed, center lines 0.18 mm chain.
- The title block contains the project, title, drawing number, revision, scale, units, projection, sheet, author, date, material or notes, and license.
- Every sheet and every render names the project and its GitHub repository (from `repo:` in `project.yaml`), at the top of the sheet and in the title block, so a printed or forwarded sheet is never anonymous.
- The drawing title names the device, not only the drawing type (for example "Handheld near-infrared resin scanner: general arrangement").
- Every view label states its scale and viewing direction (for example "Scale 1:1; side elevation looking along +Y"), and every isometric or render states where it is seen from.
- Orthographic views generated with `add_ortho` carry overall dimensions (length and depth on the top view, height on the front view) and ISO 128 centre lines on cylinders; hidden lines are dashed. Tolerances are not shown before TRL 4.
- Sheets are exported as SVG, PDF and a 300 dpi PNG.
- The revision table in the top right of the sheet lists every revision.
- Concept sketches use the same sheet and title block and carry the label "CONCEPT, NOT FOR FABRICATION".
- Geometry comes from `cad/src/*.py` (build123d). Sheets are generated by `.kit/drawing.py` and never edited by hand.

## 7. Project codes

| Code | Project | Code | Project | Code | Project |
| --- | --- | --- | --- | --- | --- |
| TBK | ThermaBrick | PCF | PicoFlow | HLT | HelioLite |
| CCB | CharCube | DRN | DustRunner | TRT | TremorTrace |
| STC | StepCue | FXH | FlexHand | CPD | ColdPod |
| SCL | SunClave | STR | SteamRoot | GGD | GrainGuard |
| SDL | SeedLine | ZBX | ZeerBox | RMS | RootMesh |
| DWD | DewDrive | SSK | StillStack | PPR | PotPress |
| WWT | WaterWatch | LMF | LumaFlow | FCL | FieldCell |
| CNP | ConePro | CVC | CulvertCrawl | EGD | EmberGuard |
| SNF | SnapFrame | CGM | CargoMule | SCM | StepClimber |
| SWC | SwapCell | PLP | PalletPilot | FTK | FlatTrike |
| WWK | WaterWalker | GRR | GrowRider | SSP | SunSpoke |
| SGN | StepGen | PBX | PowerBox | WML | WasteWise-ml |
| WSC | WasteWise Scan | RFE | ReflowEconomy | | |
| OHP | Portfolio-wide | | | | |

## 8. Build and publish

- `python .kit/render.py` checks every controlled document and renders it to `docs/pdf/<doc_id>_v<version>.pdf`.
- `python .kit/drawing.py` (called from each project's `cad/src/sheets.py`) builds drawing sheets as SVG and PDF in `cad/drawings/`.
- The GitHub Action in `.github/workflows/docs.yml` runs the checks on every push and attaches PDFs to a GitHub Release whenever a release tag is pushed.
- Public releases follow section 14: `python .kit/release_gate.py` must pass, and the release tag is `v0.<TRL>.0` (for example `v0.3.0` at TRL 3).

## 9. Technology Readiness Level (TRL)

Each project states its maturity as a Technology Readiness Level on the NASA and US DOE 1 to 9 scale. The TRL rates this specific design, not the underlying technology. A sand battery is commercial elsewhere, but a new sand battery design starts at TRL 2 until evidence shows otherwise.

| TRL | Definition | Evidence the repo must contain |
| --- | --- | --- |
| 1 | Basic principles observed | Problem statement (PRB) |
| 2 | Technology concept formulated | Draft precis (PRC) and requirements (REQ) |
| 3 | Analytical or experimental proof of concept | Calculation note (CAL), working build123d model with STEP export, drawing sheet (DWG), priced BOM with every unit cost filled in, prototype build plan (BLD) with pictures, `design_state: constructable` |
| 4 | Components validated in the lab | Test report (TST) with `environment: lab`, build log entries |
| 5 | Validated in a relevant environment | Test report (TST) with `environment: relevant` |
| 6 | System prototype demonstrated in a relevant environment | Precis at version 1.0 or later with status Released, a drawing at a lettered revision (Rev A or later), and a system-level TST with `environment: relevant` |
| 7 to 9 | Operational demonstration through proven in service | Beyond portfolio scope; claim only with a named deployment partner and evidence |

Rules:

- `project.yaml` records `trl` (current level), `trl_target` (the level the current effort aims for) and `trl_evidence` (the files that support the claim).
- `python .kit/render.py --check` fails if the evidence for the claimed TRL is missing. CI runs this check on every push.
- Documentation alone cannot go past TRL 3. TRL 4 and above require hardware and a test report.
- TRL and visibility are independent. A repo can be public at TRL 3 as a documented design ready to build.
- A change of TRL is recorded in the build log with the date and the evidence that justified it.

## 10. Portfolio phase and TRL cap

`.kit/PHASE.yaml` sets the current phase. During the **populate** phase every repo is capped at **TRL 3**: `trl` and `trl_target` may not exceed 3, and the check fails if they do. Every repo targets the cap: `trl_target` must equal 3, so a new repo is taken all the way to TRL 3 (scaffold, populate and advance, see `/to-trl3`). Work that belongs to TRL 4 or later (building or testing hardware, test articles, test plans and reports, build-log entries, purchasing lists, PCB layouts) must not be started. The prototype build plan (BLD, section 18) is TRL 3 paper work and is required. Where it already exists it is kept, flagged in the check output, and not extended. Only Amish changes `PHASE.yaml`.

Every repo carries a `CLAUDE.md` with the working rules for AI sessions: the TRL cap, decision rights (nothing is recorded as decided unless Amish decided it), one step per session, and a mandatory `docs/REVIEW.md` before stopping.

## 11. Concept media

Every repo at TRL 2 or above explains its idea visually. Media are generated from a build123d massing model with `.kit/concept.py`, never drawn by hand, so they stay in step with the design.

| File | Required | Purpose |
| --- | --- | --- |
| `media/hero.png` | TRL 2+ | Shaded isometric render with a 1.75 m person for scale; the website card image |
| `media/concept-blueprint.png` and `.pdf` | TRL 2+ | Blueprint concept sheet: orthographic and isometric views, scale, key figures, title block |
| `media/model.glb` and `media/viewer.html` | TRL 2+ | Interactive 3D viewer (glTF plus model-viewer) for the website |
| `media/cutaway.png` | When the inside matters | Section view showing internal parts |
| `media/exploded.png` | Recommended | Exploded view with numbered callouts matching the BOM |
| `media/flow.png` | When energy or material moves | System, energy or material flow diagram with losses |

Session commands in `.claude/commands/` (`/populate`, `/advance-trl3`, `/rein-in`, `/refresh-media`) carry the standard prompts, so every Claude Code session starts from the same instructions.

At TRL 2 a massing model is enough: correct overall proportions and main components. All concept media carry "CONCEPT, NOT FOR FABRICATION". The check warns when required media are missing at TRL 2 and fails at TRL 3.

## 12. Product renders

Every repo at TRL 3 shows the product as it would look, not only as a massing model.

- `cad/src/product_model.py` is the appearance model. It defines `product_parts()` (named parts with a shape and a material), `TITLE` ("Name: what it is") and `RENDER_VIEWS`. It is for renders only: every main dimension comes from `cad/src/model.py`, never typed in again.
- Where the appearance model departs from `model.py` (a chamfer, a label, a fastener drawn for realism), record the deviation in `docs/REVIEW.md` as "Proposed, awaiting Amish".
- Scale comes from context, not from a floating figure: a hand or forearm for handheld objects, and the posed mannequin (`mannequin()` in `.kit/context_parts.py`: stand, walk, push, ride, sit, reach) for anything a person uses at body scale.
- Renders are made with `.kit/export_views.py` (one scene per view) and `.kit/photoreal.py` (Blender Cycles), then captioned with `.kit/photo_caption.py`. Files are `media/render-<view>.png`; `media/render-hero.png` is required.
- Every caption names the project, the repository and the viewing direction, and carries "CONCEPT, NOT FOR FABRICATION".
- Captions never sit on the render. `.kit/photo_caption.py` adds a header band (title, concept label, repository) above the render and a footer band (view note) below it, wraps every line to the image width, and steps the font down to a floor before adding a line.
- The README opens with `media/render-hero.png`.
- Software-only and scene repositories (no single product) may use a scene render as the hero instead of a product model.

## 13. Storefront images

Two images, both made from `media/render-hero.png` by `python .kit/cards.py .`:

| File | Size | Purpose |
| --- | --- | --- |
| `media/card.png` | 800 x 800 | Square thumbnail for the organization profile page |
| `media/social-preview.png` | 1280 x 640, under 1 MB | GitHub social preview, shown when a repository link is shared |

- The social preview shows the area, name, one-line description, the first sentence of the pitch, the brand line and the repository address. Design Molecule repos read "Design Molecule · open hardware concept, TRL n"; OpenRatio repos read "OpenRatio · research and educational prototype, TRL n".
- GitHub has no API for the social preview. Upload it under the repository's Settings, Social preview, on release day.
- Regenerate both images whenever `render-hero.png` changes.

### Image quality

Every render, card and social preview must be clear and readable. `python .kit/image_qc.py` checks each one, and the release gate blocks on any failure:

| Check | Rule |
| --- | --- |
| Layout | Made by the current `photo_caption.py` or `cards.py`, which store the text layout in the PNG |
| Text inside the image | Every line at least 1.2 % of the image width from each edge; nothing runs off the side |
| No overlap | No line of text touches another line, and no caption text sits on the render |
| Text size | Render captions at least 1.05 % of the image width in pixel height (17 px at 1600 px); social preview text at least 16 px |
| Resolution | Renders at least 1200 px wide; card 800 x 800; social preview 1280 x 640 and under 1 MB |
| Sharpness | The render is not blurred or upscaled (edge sharpness at least 15 on the `image_qc.py` scale) |

Long titles and notes wrap to more lines rather than shrinking below the floor. The social preview shortens the pitch sentence with an ellipsis only if it cannot fit at the smallest size.

## 14. Public release

A repository goes public only when Amish approves it, and only after `python .kit/release_gate.py` passes. The gate checks:

1. `render.py --check` passes (document control, TRL cap, concept media).
2. Storefront: hero render, card, social preview under 1 MB, README leading with the hero, and every image passing the image quality check (section 13).
3. Issue templates in `.github/ISSUE_TEMPLATE/`: question, build report, design suggestion. The build report template restates that the design is a TRL 3 concept, not released for fabrication (OpenRatio: a research and educational prototype, not a medical device).
4. `CITATION.cff` valid, with an author ORCID.
5. License files match `project.yaml`.
6. No em dashes in the repository's own text.
7. BioMedical and OpenRatio repos use soft, non-clinical wording: "research and educational prototype, not a medical device".
8. No secrets anywhere in the history (gitleaks).
9. No links to sibling repositories that are still private.
10. REUSE files present (`REUSE.toml`, `LICENSES/`, `.github/workflows/reuse.yml`) and `reuse lint` passes (section 16).
11. `CITATION.cff` names exactly one license, because Zenodo rejects a list (section 17).

It warns, without blocking, when the README lacks a Safety heading or a "not for fabrication" statement, when `CITATION.cff` has no DOI yet, and when the README lacks the Zenodo DOI, REUSE or Software Heritage badge, so a person can confirm.

On release day, per repository:

- A signed, annotated tag `v0.<TRL>.0` on `main`.
- A GitHub release with short notes (what it is, TRL, status, licenses, how to cite) and a design pack, `<repo>-v0.<TRL>.0-design-pack.zip`, holding `cad/step`, `cad/drawings`, `docs/pdf`, `bom`, README, licenses and `CITATION.cff`.
- Description from the first sentences of `pitch` (350 characters at most), website `https://designmolecule.com` (OpenRatio: `https://openratio.ai`), topics from `project.yaml`.
- Before the first release, the repository is switched on in Zenodo (section 17), so the release is archived and gets a DOI.
- Visibility switched to public last, after the release exists.
- The social preview uploaded and the organization profile updated with the new cards.
- After the release: the concept DOI written to `CITATION.cff` and a Software Heritage save requested (section 17).

The internal working files (`CLAUDE.md`, `.kit/CLAUDE.md`, `.claude/commands/`, `docs/REVIEW.md`) stay public, and open "Proposed, awaiting Amish" items stay visible as open questions (Amish, 2026-09-27).

## 15. Authorship, citation and signing

- Amish Chadha is the author of every design, ORCID 0009-0000-8079-7141. Commits are authored as Amish Chadha <amish@designmolecule.com>.
- `CITATION.cff` lists Amish (with ORCID) first, then any credited contributors; `CONTRIBUTORS.md` and the README Credits section agree with it.
- `CITATION.cff` names one license: the hardware license (CERN-OHL-S-2.0), or the software license in a software-only repository. The full split between hardware and software licenses lives in `REUSE.toml` and the README. Once the repository is archived, `CITATION.cff` carries the concept DOI in `doi:`.
- Work done with Claude carries the trailer `Co-Authored-By: Claude <noreply@anthropic.com>` (with the model name), and the README Credits section says designs are developed with AI assistance.
- Every commit and tag pushed to GitHub is signed with Amish's SSH signing key, so GitHub shows it as Verified. Commits prepared elsewhere are re-signed on Amish's Mac before they are pushed.
- Once a repository is public, its history is never rewritten.

## 16. Licensing metadata (REUSE)

Every file states its copyright and license in a machine-readable way, following the REUSE Specification 3.3 (https://reuse.software). A repository is set up with:

```
python .kit/archive.py reuse
```

This writes three things and adds the REUSE and Software Heritage badges to the README badge line:

- `REUSE.toml`, built from the licenses in `project.yaml`. Everything is under the hardware license by default. Scripts, firmware, notebooks, web viewers, workflows and agent commands are under the software license. `cad/` and `electronics/` stay under the hardware license even where they are written as Python. The bundled IBM Plex fonts are OFL-1.1 (IBM Corp.). Copyright is "<first commit year> Amish Chadha".
- `LICENSES/`, with the full text of each license used (`reuse download`). The root `LICENSE` and `LICENSE-SOFTWARE` files stay for GitHub's license detection.
- `.github/workflows/reuse.yml`, which runs the REUSE check (fsfe/reuse-action) on every push and drives the README badge.

A new kind of file that falls outside these rules gets a new annotation in `REUSE.toml` rather than a header comment. `reuse lint` must pass before every commit that adds files, and the release gate enforces it.

## 17. Archiving and DOI (Zenodo and Software Heritage)

Every public repository is archived twice, so the design stays citable and retrievable if GitHub changes.

Zenodo (a citable DOI for each release):

1. Amish's Zenodo account is linked to GitHub. Before the first release, Amish switches the repository on in Zenodo (Account, GitHub). Only Amish changes Zenodo or GitHub settings.
2. Run `python .kit/archive.py zenodo`: it makes sure `CITATION.cff` names one license and adds the Zenodo DOI badge, which uses the GitHub repository ID and always points at the latest version. Zenodo reads its metadata (title, authors with ORCID, license, keywords) from `CITATION.cff`, and rejects the whole archive when that file lists several licenses.
3. Publish the GitHub release (section 14). Zenodo archives it within minutes and mints two DOIs: a version DOI for that release and a concept DOI that stands for all versions.
4. Check the Zenodo record: title, author and ORCID, license, keywords. If Zenodo shows "Citation metadata load failed", fix `CITATION.cff`, validate it with cffconvert and publish a new patch release (for example `v0.3.2`); a failed release is never re-used.
5. Run `python .kit/archive.py zenodo --doi <concept DOI>` and commit, so GitHub's "Cite this repository" and every future archive carry the concept DOI. Every later release gets its own version DOI automatically; the concept DOI never changes.

Software Heritage (permanent source archive):

1. After the repository is public, request a save at https://archive.softwareheritage.org/save/ (origin type git, the repository URL). Anonymous requests are limited to about ten an hour, so batches are spread out.
2. The Software Heritage badge on the README resolves once the save is accepted and ingested. Later pushes are picked up by its regular crawl.

OpenRatio repositories follow the same steps when Amish approves their release.

## 18. Prototype build plan (BLD) and the constructable design

### Two design states

A design moves through two states, recorded as `design_state` in `project.yaml`:

- **Concept**: the design shows what the product does and that it works on paper (TRL 2 and the calculations of TRL 3). Parts may be simplified shapes that have never been checked for how they are made or how they join.
- **Constructable**: every part can be made with the stated process and material, and every part fits and fastens to the parts next to it. Nothing is left as a shape that cannot be cut, cast, bent, printed, machined or bought.

A repo reaches TRL 3 only when its design is constructable and its build plan shows how. Writing the build plan is how the design is made constructable: when a part cannot be made or cannot fit as modelled, change the model so it can (Amish, 2026-09-30: "fix the design assumptions to match and be physically feasible"), keep what the concept does, and record every change in a decision record "Design for construction" (DDR) and in the plan. Changes that alter what the product does, its pitch or its safety case are proposed, not made.

### What the build plan is

`docs/05-build-plan.md` (`PRJ-BLD-001`) tells a capable maker how to build the first proof-of-concept prototype, in order, component by component, and shows it in pictures. It is written before anything is built, states "Plan, not yet built" under the title and never claims results. Building and testing to it is TRL 4 work.

### Writing rules

- **Plain English.** Say "the steel plate the jack stands on", not a model parameter or variable name. No code identifiers, function names, parameter names or file paths in the body of the plan. Give sizes as numbers with units ("a 62 mm hole, centred 100 mm up from the bottom edge"). The only place file names appear is the closing "Where the numbers come from" list.
- **Pictures first.** Every component and every assembly step has a picture. A reader should be able to build from the pictures, with the words explaining what the pictures cannot show (order, force, tolerance, checks).
- **By component, in build order.** Each component is made and checked before the step that needs it.
- **Cost is not the focus.** One line in the overview may state the parts cost from the BOM; there is no cost or time section.

### Sections, in order

1. **What you are building**: the overview picture (every component pulled apart and numbered in build order) and one short paragraph.
2. **What changed to make it buildable**: a table of each change from the concept (what the concept had, what the constructable design has, why), with a picture where the change is visible. "None" if nothing changed.
3. **Making the components**: one subsection per made component, in build order, each with:
   - its making sketch (three views with overall sizes, a 3D view, where it goes, making notes), `cad/drawings/PRJ-DWG-1NN`;
   - what it is and what it is made from (material, stock size);
   - how to make it, as numbered steps (mark out, cut, drill, bend, weld, cast, print, machine, finish), with the sizes that matter;
   - how it fits the parts next to it: a close-up picture of the joint, which faces touch, what holds them (bolt, weld, pin, clip, glue), the gap or fit needed, and which side goes where;
   - the check before moving on.
   Bought components get a short subsection: what to buy (specification, not brand), and what to do to it (drill, trim, fit).
4. **Putting it together**: numbered assembly steps, each with a step picture (parts already fitted in grey, the part being fitted in colour with an arrow showing the way it goes in), the fasteners, and any hold point.
5. **First checks**: fit, movement, first power or first load, each tied to a requirement ID with a pass criterion. The plan lists them; a TRL 4 test report records them.
6. **Safety stops**: points where work stops (before energising, pressurising, loading, lifting or operating) and what must be true to carry on.
7. **Tools, skills and workspace.**
8. **Where the numbers come from**: the model, drawings, calculation note and BOM, by file name.
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

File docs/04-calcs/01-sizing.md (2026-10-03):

---
doc_id: RMS-CAL-001
title: RootMesh sizing calculations
project: RootMesh
doc_type: Calculation
version: "0.5"
status: Draft
date: '2026-10-02'
author: Amish Chadha
license: CERN-OHL-S-2.0
revisions:
- version: "0.1"
  date: '2026-09-25'
  author: Amish Chadha
  change: First issue for TRL 3 (airtime, energy, radio link, EC circuit, sensing geometry, thermal and sealing, installation force, cost)
- version: "0.2"
  date: '2026-09-25'
  author: Amish Chadha
  change: Recommendations accepted by Amish (DDR-002); slot tool force case, cell depth check for R9, pilot set cost with the slot tool
- version: "0.3"
  date: '2026-10-01'
  author: Amish Chadha
  change: Re-run for the constructable design (RMS-DDR-003); push depth, head air volume, cell depth check and cost updated; budget treated as a value-engineering target
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

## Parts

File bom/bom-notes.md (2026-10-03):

# BOM notes

`bom.csv` prices one **pilot set**: three sensor stakes and one gateway, which is how the USD 300 value-engineering target (`budget_usd`, a hypothetical control target, not a limit) is read (decided by Amish, 2026-09-25; RMS-DDR-001, D4). Quantities are for the whole set; the notes column gives the count per stake. Rows 1 to 12 match the numbered callouts in `media/exploded.png`. Rows 13 to 17 (gateway, dashboard, slot tool, head fixings and bonding, and the status LED and resistor) are not in the exploded view. Every row is priced.

| Group | Indicative cost |
| --- | --- |
| One stake (rows 1 to 12, 16 and 17) | $59.15 |
| Three stakes | $177.45 |
| Gateway (row 13) | $90.00 |
| Slot tool (row 15), one per set | $14.00 |
| **Pilot set total** | **$281.45** (value-engineering target USD 300; USD 18.55 under the target) |

The totals are computed from `bom.csv` by `docs/04-calcs/sizing.py` (RMS-CAL-001, [H1]).

Changes at TRL 3: row 4 is now the antenna and feed on the marker rod (sleeve dipole, 1.2 m RG174 lead, gland and clip, $7.00 instead of $4.00; RMS-DDR-001, D2), and row 12 adds an ePTFE vent membrane ($5.00 instead of $4.50; RMS-CAL-001, section F).

Change on 2026-09-25 after Amish accepted the recommendations (RMS-DDR-002): row 15 adds a steel slot tool ($10.00, one per pilot set) that pre-cuts the fin path so the fin needs less push force (RMS-CAL-001 v0.2, section G). The pilot set rises from $256.50 to $266.50.

Change on 2026-10-01 for the constructable design (RMS-DDR-003): row 2 is now a printed head body and cap ($3.50, was $3.00); row 7 is a fin printed in two halves ($3.00, was $2.50); rows 4, 5, 11 and 12 re-described (antenna clips, cell holder, cable ties, 64 x 2 mm O-ring and M8 gland); row 15 adds a cross-hole handle with two shaft collars and a thumb-screw depth stop ($14.00, was $10.00); new row 16 carries the heat-set inserts, cap screws, sealing washers, epoxy, heat-shrink and prototype board ($2.50 per stake). One stake rises from $55.50 to $59.00 and the pilot set from $266.50 to $281.00.

Changes on 2026-10-02 from the decisions of that day: the cell is chosen (row 5, IFR14500EC class, datasheet discharge -20 to +60 C, so the printed shade skirt is not needed); the radio is US915 (row 3 band plan, row 4 dipole cut to 164 mm, row 13 the US915 gateway; no price changed); new row 17 adds the status LED and its resistor ($0.15 per stake). One stake rises from $59.00 to $59.15 and the pilot set from $281.00 to $281.45. Mass is not tracked in the bill of materials; the printed head body gains a 5.2 mm hole and loses about 0.1 cm3 of material.

All prices are indicative 2026 retail estimates in USD for single or small quantities, without shipping or tax. Suppliers are named where known and otherwise given as a supplier type. Printed parts are costed as material only. Tools (3D printer, soldering iron, hand auger) are not included.

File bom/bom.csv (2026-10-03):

item | qty | spec | supplier | unit_cost_usd | make_buy | notes
1 Solar panel | 3 | 5 V, 0.5 W monocrystalline, about 70 x 50 mm, epoxy or PET laminate | Online electronics retailer (AliExpress or Amazon class) | 3.00 | buy | Indicative price; 1 per stake
2 Head enclosure | 3 | 3D-printed ASA head in two parts: body (72 mm diameter, socket over the 42 mm tube, cavity, two board guide slots, two insert bosses, gland and vent bosses) and cap (30 degree sloped top with panel recess, O-ring groove, two screw counterbores) | Self | 3.50 | make | Material cost only; ASA for UV and heat; body and cap from RMS-DDR-003 (one-piece head could not take the board); 1 set per stake
3 Controller board | 3 | LoRaWAN module (STM32WLE5 class, e.g. Seeed Wio-E5) on a small carrier PCB with LiFePO4 solar charger (CN3058E class with NTC cut-off), sensor power switch, EC drive and a 2 mA status LED output; US915 band plan (902 to 928 MHz) | Seeed Studio or distributor (Mouser, DigiKey); PCB service (JLCPCB class) | 15.00 | buy | Indicative: Wio-E5 module about $7 plus carrier PCB, CN3058E charger and parts about $8; module decided (RMS-DDR-001 D8); LED output added 2026-10-02 (line 17); 1 per stake
4 Antenna and feed | 3 | 915 MHz half-wave sleeve dipole (164 mm long) held by two printed clips at the top of the marker rod, about 1 m, with 1.2 m RG174 lead and u.FL to SMA pigtail | Online electronics retailer | 7.00 | buy | Indicative: dipole about $4, 1.2 m lead and pigtail about $2.50, two printed rod clips $0.50; antenna at 1 m on the marker rod decided (RMS-DDR-001 D2); 1 per stake; cut for 915 MHz (US915) on 2026-10-02, price unchanged because dipole length does not change the part price
5 LiFePO4 cell | 3 | 14500 size, 3.2 V, 600 mAh, with PTC fuse and leads; stands in a 3D-printed ASA holder on the fin spigot | Battery distributor (for example Simpower IFR14500EC class, IMR Batteries or Amazon class) | 4.00 | buy | Indicative price; about 1.9 Wh per cell; LiFePO4 decided (RMS-DDR-001 D5); cell chosen 2026-10-02: IFR14500EC class, 600 mAh, 3.2 V, datasheet discharge range -20 to +60 C (at least 55 C, so no shade skirt) and charge 0 to +60 C (the charger still blocks charging above 45 C); 1 per stake
6 Stake tube | 3 | PVC pressure pipe, 42 mm OD (40 mm or 1-1/4 in nominal), 170 mm long | Hardware store | 1.50 | buy | Indicative price; 1 per stake
7 Sensor fin | 3 | 3D-printed PETG or ASA carrier in two halves glued on the mid-plane: blade 36 x 12 x 310 mm with two 19 mm sensing windows, probe slots, wire channels, temperature probe bore and rod grooves; 42 mm collar and 35.4 mm spigot at the top | Self | 3.00 | make | Material cost only; two halves from RMS-DDR-003; needs a print bed of at least 300 x 300 mm (halves laid diagonally); 1 per stake
8 Capacitive moisture probe | 6 | Capacitive soil moisture sensor v1.2 class, NE555 swapped for TLC555, edges sealed in epoxy | Online electronics retailer | 3.00 | buy | Indicative price including TLC555 and epoxy; 2 per stake (150 and 300 mm)
9 EC electrode | 6 | 316 stainless steel rod, 4 mm diameter, 80 mm long, 24 mm spacing | Metal supplier | 1.50 | buy | Indicative price; 2 per stake
10 Temperature probe | 3 | DS18B20 in 6 mm stainless sheath, 1 m cable | Online electronics retailer | 2.50 | buy | Indicative price; 1 per stake
11 Marker rod and flag | 3 | Fiberglass rod, 8 mm diameter, 1.2 m, high-visibility flag; four cable ties hold the antenna lead to the rod | Farm or garden supplier | 3.00 | buy | Indicative price; 1 per stake
12 Seals and consumables | 3 | 64 x 2 mm O-ring (cap face seal), M8 IP68 cable gland for 2 to 4 mm cable (antenna lead), adhesive ePTFE vent membrane, desiccant sachet, potting epoxy, wire | Hardware store; ePTFE vent from an online electronics retailer | 5.00 | buy | Indicative price; includes an adhesive ePTFE vent membrane (RMS-CAL-001 section 8); 1 per stake
13 LoRaWAN gateway | 1 | Indoor 8-channel LoRaWAN gateway, US915 variant, with Wi-Fi backhaul and USB supply (The Things Indoor Gateway US915 class), with its stock 915 MHz antenna | Seeed Studio or distributor | 90.00 | buy | Indicative price (about $79 list plus supply); one per farm; not shown in the exploded view; TTN with a TTIG-class gateway decided for the pilot (RMS-DDR-001 D3); US915 variant specified 2026-10-02 (price unchanged, same list price in both bands); gateway antenna is part of the gateway
14 Dashboard software | 1 | Open-source dashboard (for example Node-RED or Grafana) on an existing computer, fed from the network server | Open source | 0.00 | make | No hardware cost; not shown in the exploded view
15 Slot tool | 1 | Installation tool: 32 x 8 mm mild steel flat bar, 650 mm, ground to a point, 20.5 mm cross hole; 20 mm steel round bar handle, 250 mm, through the hole between two 20 mm shaft collars; printed ASA depth stop, 80 mm diameter, clamped by an M5 thumb screw | Hardware store or metal supplier; collar self-printed | 14.00 | make | Indicative: flat bar about $6, handle bar $2, two shaft collars $3, thumb screw and nut $1, depth stop material $1, drill and grind consumables $1; one per pilot set, not part of the installed stake; handle and stop fixings from RMS-DDR-003; driven with a mallet through the auger hole to pre-cut the fin path, then withdrawn (RMS-DDR-002); not shown in the exploded view
16 Head fixings and bonding | 3 | Two M3 brass heat-set inserts, two M3 x 12 stainless button-head screws with EPDM sealing washers (cap), structural two-part epoxy (fin halves, fin into tube, tube into head), 4 mm heat-shrink sleeve (EC rods), 56 x 40 mm prototype board for the controller modules | Hardware store; online electronics retailer | 2.50 | buy | Indicative; added for construction (RMS-DDR-003); 1 set per stake
17 Status LED and resistor | 3 | 5 mm green diffused LED (2.1 V, 20 mA class) in a 5.2 mm lens hole in the head body wall, flange inside, and one 560 ohm 0.25 W axial resistor on the controller board; about 2.1 mA when lit | Online electronics retailer | 0.15 | buy | Indicative: LED about $0.10 and resistor about $0.02 plus leads and solder, rounded up; added 2026-10-02 (decision 6); 1 set per stake; not in the exploded view callouts of rows 1 to 12

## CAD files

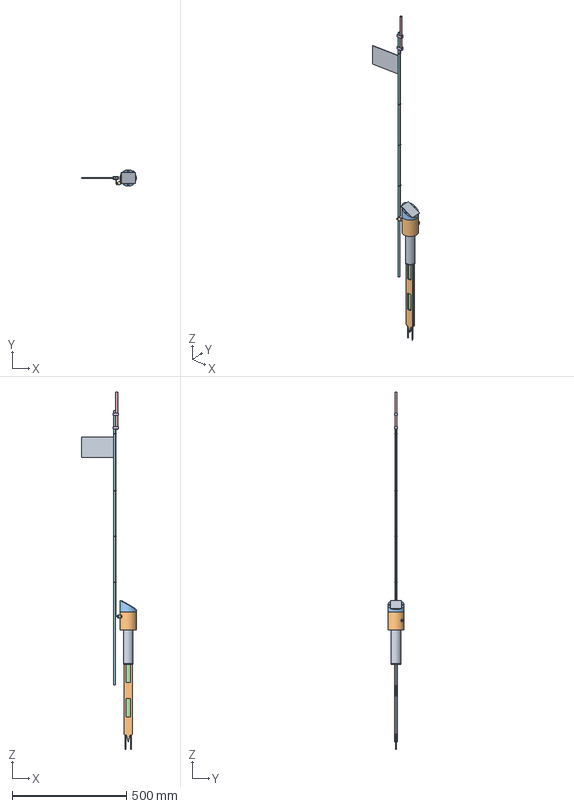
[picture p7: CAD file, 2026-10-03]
cad/step/rootmesh-stake-assembly.step
240.0 x 72.0 x 1567.0 mm
Stake tube
Fin front half
Fin back half
Moisture probe, upper
Moisture probe, lower
EC electrodes (2)
Insulating sleeves
Temperature probe
Cell holder
LiFePO4 cell
Head body
Head cap
O-ring
Heat-set inserts (2)
Cap screws and sealing washers (2)
Coax gland
Solar panel
Controller board
Status LED, green 5 mm
LED series resistor, 560 ohm
Sleeve dipole
Antenna clips (2)
Antenna lead (RG174)
Marker rod
Flag
Cable ties

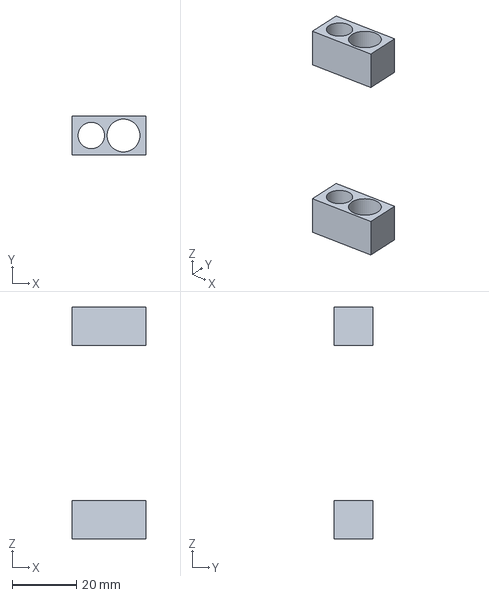
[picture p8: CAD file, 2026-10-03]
cad/step/antenna-clip.step
23.0 x 12.0 x 72.0 mm

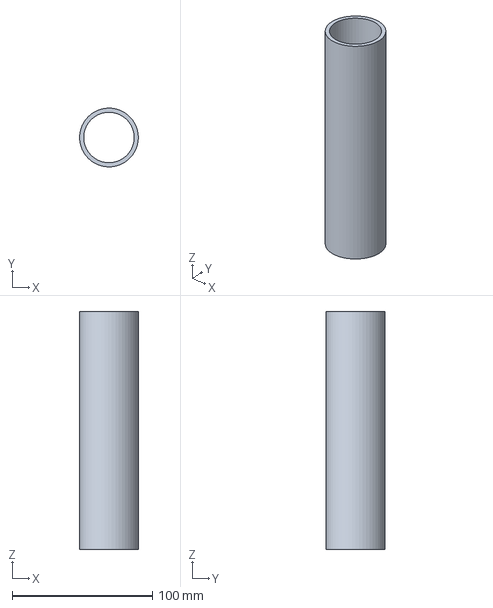
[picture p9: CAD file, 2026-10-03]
cad/step/stake-tube.step
42.0 x 42.0 x 170.0 mm

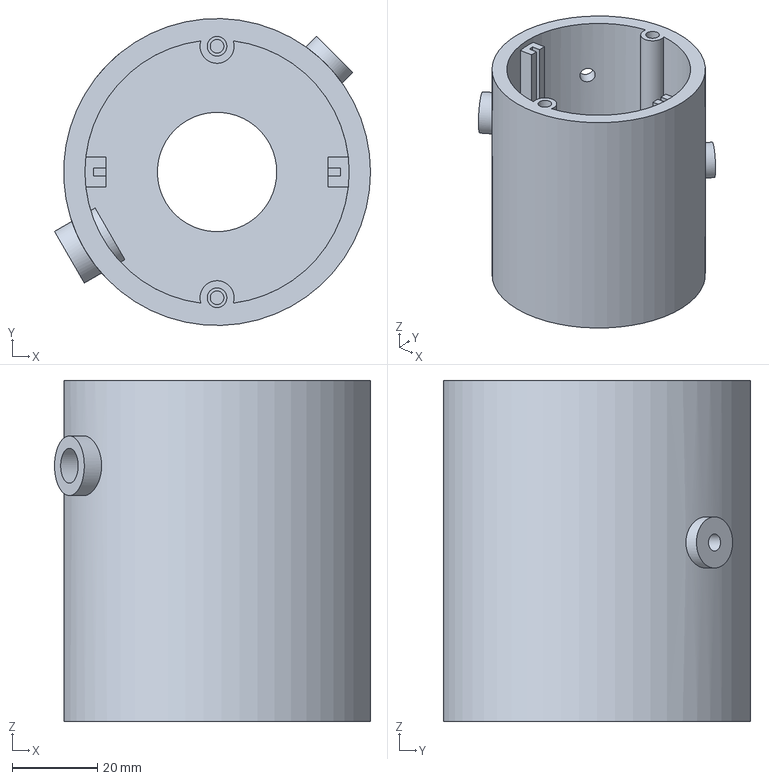
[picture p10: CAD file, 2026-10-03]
cad/step/head-body.step
74.1 x 72.0 x 80.0 mm

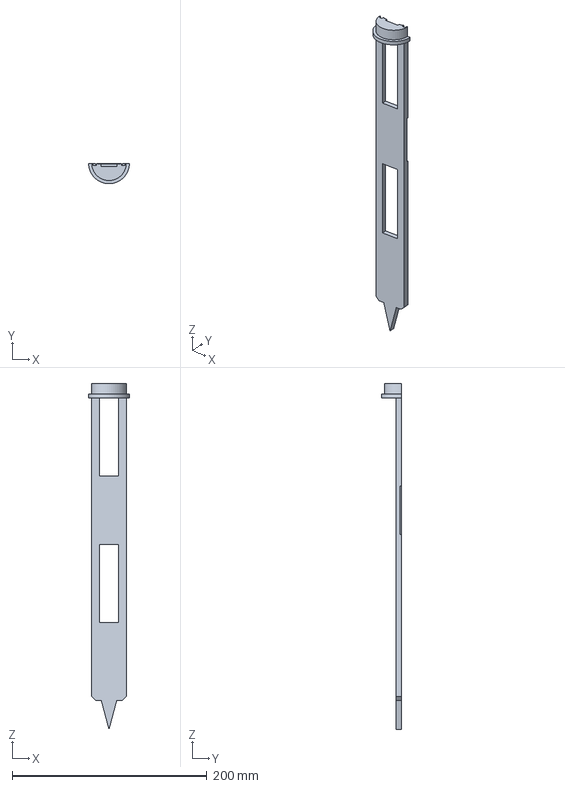
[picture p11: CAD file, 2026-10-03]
cad/step/sensor-fin-front.step
42.0 x 21.0 x 355.0 mm

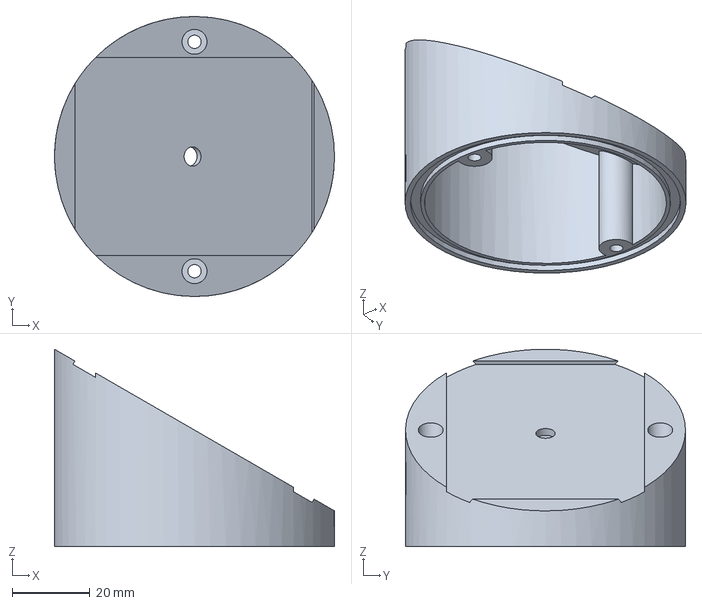
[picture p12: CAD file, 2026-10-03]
cad/step/head-cap.step
72.0 x 72.0 x 50.8 mm

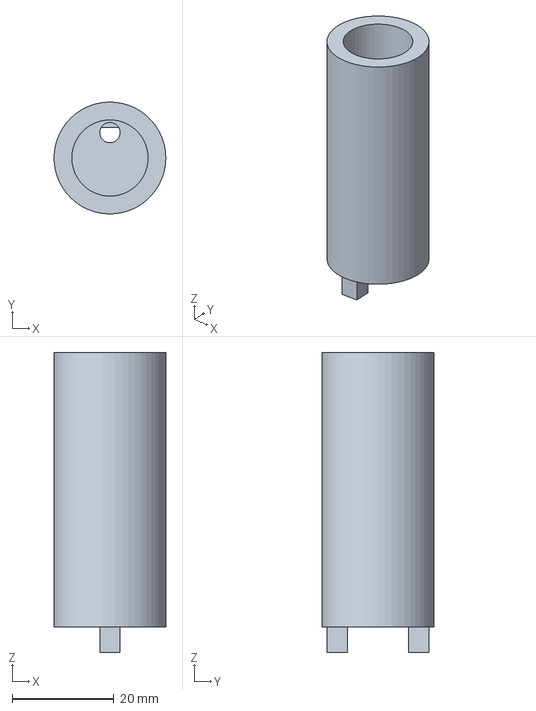
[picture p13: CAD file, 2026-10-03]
cad/step/cell-holder.step
22.0 x 22.0 x 59.0 mm

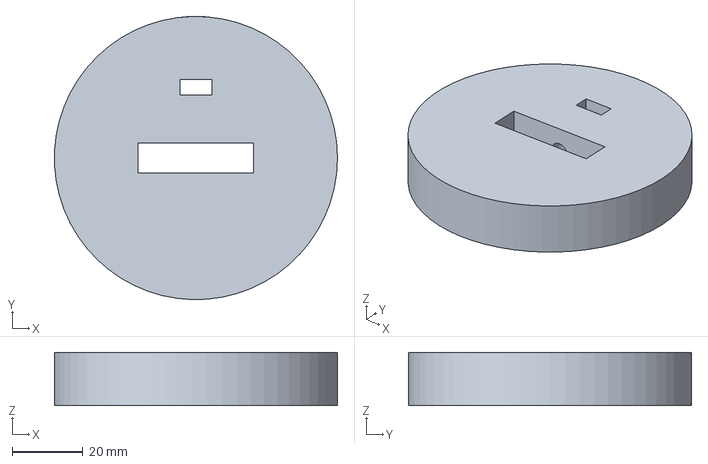
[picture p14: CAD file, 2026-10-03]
cad/step/slot-tool-stop.step
79.9 x 80.0 x 15.0 mm

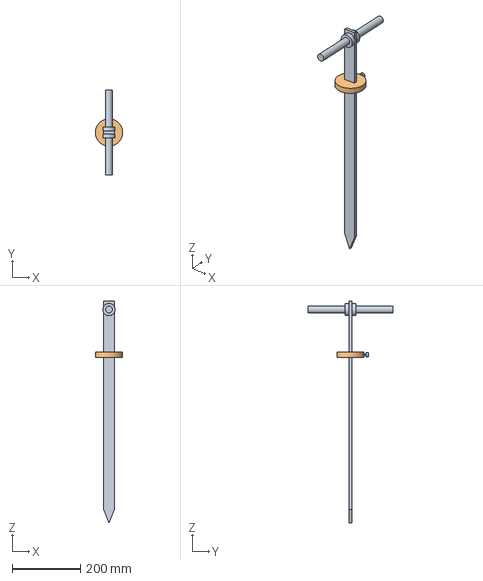
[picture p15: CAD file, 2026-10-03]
cad/step/slot-tool.step
79.9 x 250.0 x 650.0 mm

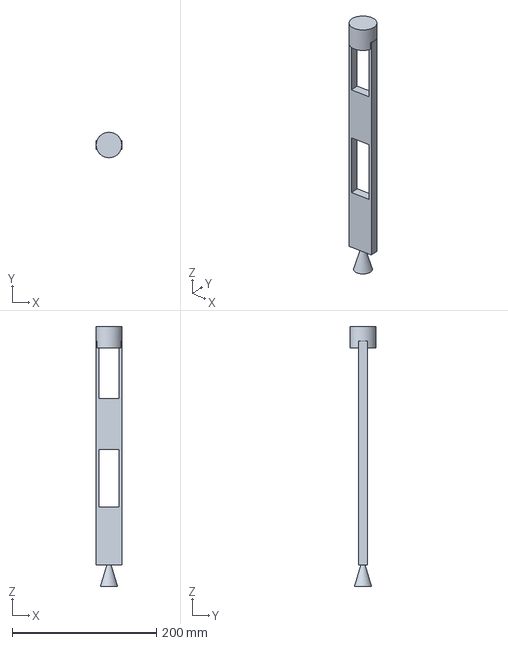
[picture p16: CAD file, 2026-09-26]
cad/step/sensor-fin.step
36.0 x 35.4 x 360.0 mm

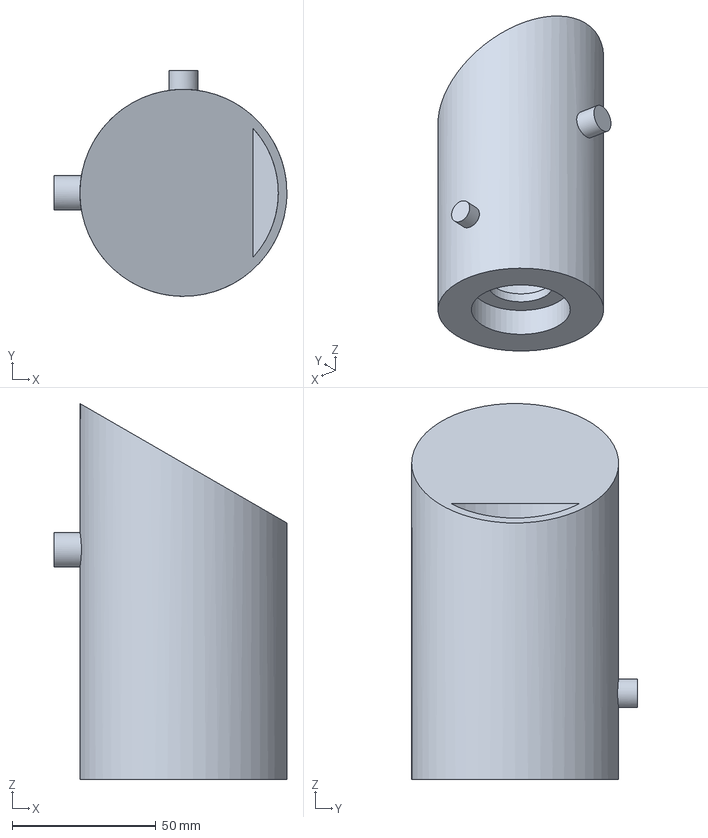
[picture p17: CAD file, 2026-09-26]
cad/step/head-enclosure.step
81.0 x 78.5 x 130.8 mm

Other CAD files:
cad/step/sensor-fin-back.step
cad/stl/antenna-clip.stl
cad/stl/cell-holder.stl
cad/stl/head-body.stl
cad/stl/head-cap.stl
cad/stl/head-enclosure.stl
cad/stl/rootmesh-stake-assembly.stl
cad/stl/sensor-fin-back.stl
cad/stl/sensor-fin-front.stl
cad/stl/sensor-fin.stl
cad/stl/slot-tool-stop.stl
cad/stl/slot-tool.stl
cad/stl/stake-tube.stl

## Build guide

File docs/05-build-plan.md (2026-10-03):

---
doc_id: RMS-BLD-001
title: RootMesh prototype build plan
project: RootMesh
doc_type: Build plan
version: "0.2"
status: Draft
date: '2026-10-02'
author: Amish Chadha
license: CERN-OHL-S-2.0
revisions:
  - version: "0.1"
    date: '2026-10-01'
    author: Amish Chadha
    change: First build plan, with pictures by component and step; design made constructable (RMS-DDR-003)
  - version: "0.2"
    date: '2026-10-02'
    author: Amish Chadha
    change: "Decisions of 2026-10-02 carried into the plan and pictures: 915 MHz dipole and US915 gateway, cell chosen, status LED and its resistor"
---

# RootMesh prototype build plan

**Plan, not yet built.** How to build the first proof-of-concept prototype, component by component. Building and testing to it is TRL 4 work. Decisions still to be made are kept in the design decisions register ([docs/06-design-decisions.md](06-design-decisions.md)), not here.

## 1. What you are building

Figure 1. Every stake component, pulled apart and numbered in build order

*Figure 1. The 20 stake components, pulled apart and numbered in build order. The marker rod and antenna lead are drawn shortened.*

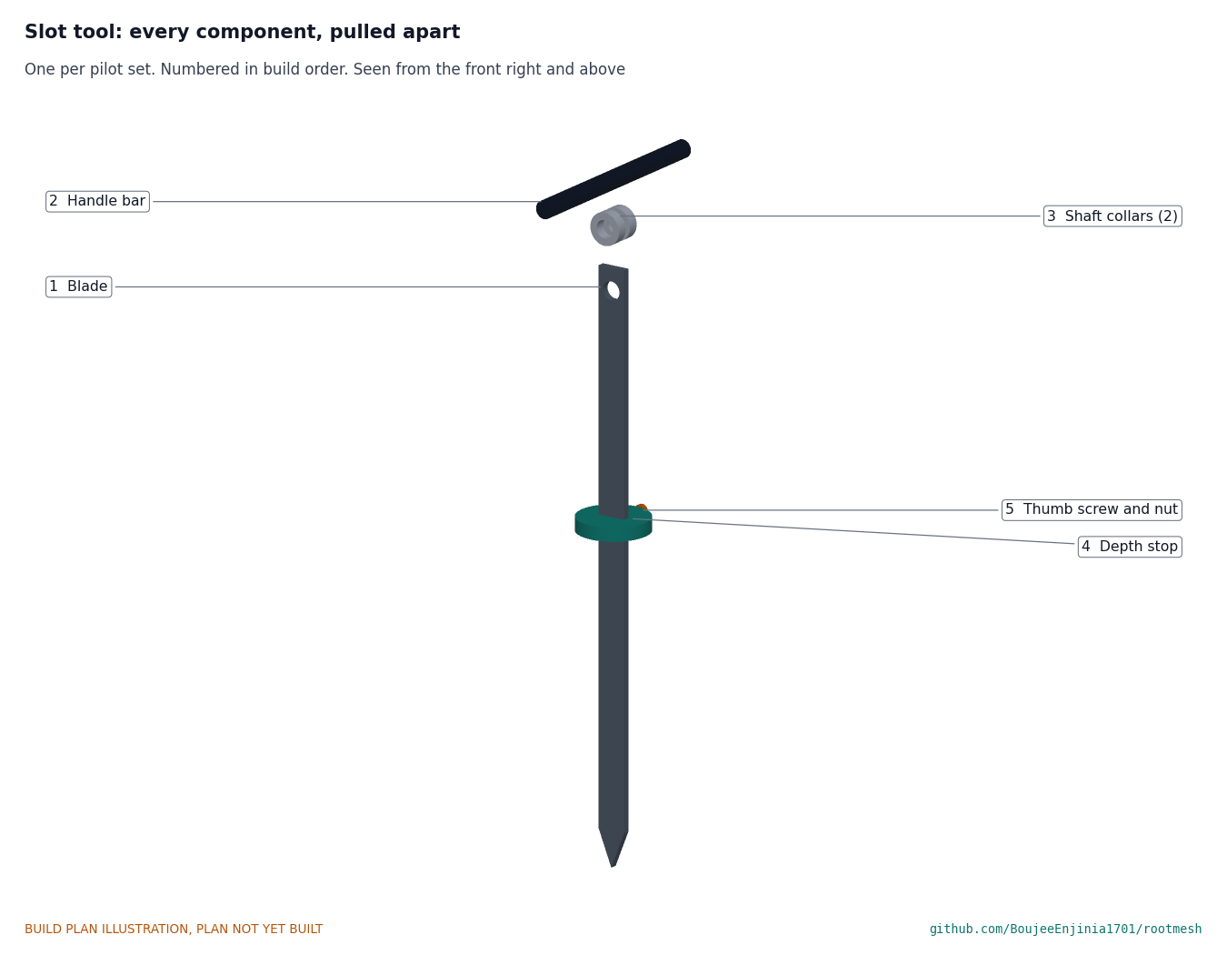
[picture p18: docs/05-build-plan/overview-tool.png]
Figure 2. The slot tool, pulled apart


*Figure 2. The slot tool, one per pilot set, used to cut the path for the fin before each stake goes in.*

The prototype is one RootMesh sensor stake, installed in a trial bed of soil, and the steel slot tool that prepares the ground for it. The stake is a flat sensor fin pushed into the soil, carrying two moisture probes, a temperature probe and two steel electrodes; a short plastic pipe above it holds a small lithium iron phosphate cell; and a printed head just above the ground holds the controller board under a cap that carries the solar panel. The antenna stands on a flagged fibreglass marker rod beside the stake. Figure 1 shows the 20 stake components in the order you make or fit them. Eight are made in a small workshop: the two halves of the fin, the head body and cap, the cell holder and the two antenna clips are 3D printed, the pipe is cut to length, and the two electrodes are cut and pointed from stainless rod. The slot tool (Figure 2) is a steel blade, a round bar handle, two shaft collars and a printed depth stop. Everything else is bought: the probes, temperature probe, cell, panel, electronic modules, antenna, status LED, O-ring, gland, inserts, screws, rod and flag. The work is 3D printing, sawing, drilling and grinding steel bar, gluing with epoxy, and soldering bought modules together. The parts cost about $59.15 a stake and $281.45 for a pilot set of three stakes, a gateway and a slot tool, from the bill of materials.

> **Safety:** The stake holds a lithium iron phosphate cell of about 1.9 Wh and its charger. Keep the cell out of its holder until section 6 says otherwise, never charge it below 0 °C or above 45 °C, and never leave a first build charging unattended. The slot tool is a pointed steel blade struck with a mallet: wear eye protection and gloves and keep feet clear of the point. Grinding steel throws sparks; grind away from anything that burns. Epoxy and printing ASA give off fumes; work in a ventilated space and wear nitrile gloves with epoxy. The fin tip and electrodes are sharp: cover them when the stake is not in the ground.

## 2. What changed to make it buildable

The concept showed what the stake does; some of its parts could not be made, fitted or fixed as drawn. Each change below keeps what the stake does (the same sensing depths, electrode spacing, cell depth, panel and antenna height), and all of them are recorded in decision record RMS-DDR-003, open for Amish's review.

*Table 1. Changes from the concept.*

| Component | The concept had | The buildable design has | Why |
| --- | --- | --- | --- |
| Head | One printed cup with only a 28 mm hole into it; an O-ring that sealed nothing; no fixing to the tube | A body bonded over the tube and a removable cap carrying the panel, sealed by an O-ring on the body rim and held by two screws (Figure 19) | The 56 mm board can now go in from the top, and the head is sealed and fixed |
| Controller board | Loose in the head | Stands in two guide slots printed in the body (Figure 15) | A fixing that needs no extra part |
| Top of the fin | Ran 10 mm inside the tube, cutting into its wall; the upper probe window reached inside the tube | A 42 mm collar the tube end sits on, and a spigot glued inside the tube; the tube moved up 14 mm (Figure 11) | Keeps the probe at 150 mm and gives the tube a stop and a sealed joint |
| Fin | Solid, with nowhere to hold the sensors or run their wires | Two printed halves glued together, with slots, pockets, wire channels, a bore and grooves inside (Figures 8 and 9) | Traps and pots every sensor and carries its wires to the tube |
| Temperature probe | Stood 7 mm proud of the fin edge, where installation would tear it off | Lies in a bore in the fin edge, 0.4 mm proud (Figure 6) | Survives installation and still touches the soil |
| Fin tip and electrodes | A round cone wider than the fin; each electrode in three loose pieces | A wedge tip between the electrodes; each electrode one 80 mm rod held in the foot (Figure 5) | The bare length and spacing that set the reading are unchanged |
| Cell | Loose in the tube | A printed holder standing on the spigot top (Figure 11) | Holds the cell at 62 mm and lifts out for a change |
| Gland and vent | The gland at the cap's parting line, in line with the board; the vent where a screw boss now is | Gland 100 mm above grade, turned toward the front; vent at the back right (Figure 16) | Both clear the board and the bosses |
| Antenna clip | A block that overlapped the rod; the lead hung in the air | Two printed clips and four cable ties (Figure 21) | A fixing that slides on by hand |
| Slot tool | A handle that passed through the blade's own plane; a loose depth stop | A bar through a cross hole with two shaft collars; a stop clamped by a thumb screw (Figures 24 and 25) | No welding; the stop can be set |
| Installation | Auger hole 120 mm deep | Auger hole 110 mm deep, to the bottom of the collar | Follows the collar; the fin is pushed 10 mm further into firm soil |

## 3. Making the components

Make and check each component before the assembly step that needs it. Sizes are in millimetres. Directions are as seen standing at the front of the stake: the panel slopes down to your right, toward the equator, and the marker rod stands on your left. The front half of the fin (the one with the electronics pockets) faces you. Depths are measured down from the soil surface, heights up from it. Workshop tolerance is 0.5 mm unless a step says otherwise; drawings do not carry tolerances before TRL 4.

### 3.1 Moisture probes (prepare 2)

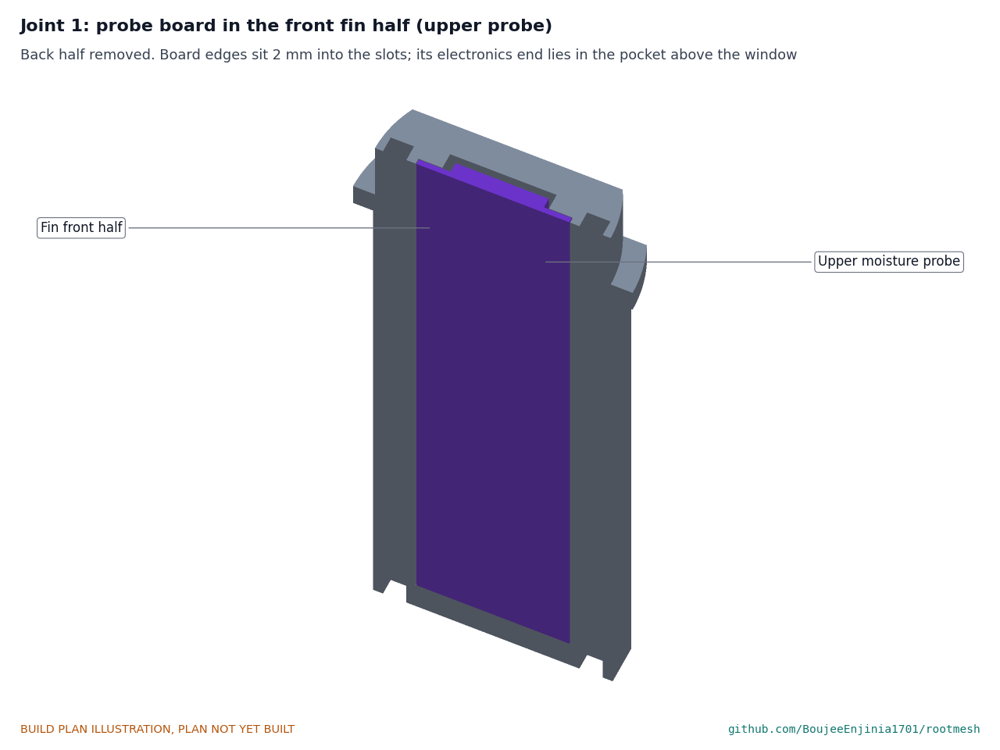
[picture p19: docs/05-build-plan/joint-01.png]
Figure 3. A probe board in the front fin half


*Figure 3. A probe board in its slots in the front half of the fin, with its electronics end in the pocket above the window (shown for the upper probe).*

**What it is and what it is made from.** A bought capacitive soil moisture board, version 1.2 class, about 23 mm wide and 98 to 100 mm long, with its parts on one face at the top end. It is changed so that it gives a frequency, not a voltage, and so that it survives in wet soil.

**How to prepare it.**

1. Remove the NE555 timer and fit a TLC555 in its place (the low-voltage CMOS version, which runs at 3.3 V and draws less current).
2. Solder a three-core lead of 0.25 mm² (24 AWG) wire, about 600 mm long, to the board's power, ground and output pads in place of its plug.
3. Paint every cut edge of the board with a thin coat of epoxy, so water cannot creep into the board's layers. Let it cure.
4. Label each lead: "upper" and "lower".

**How it fits the parts next to it.** Each board lies in the middle of the fin, its two long edges held 2 mm deep in slots in each fin half, its sensing area behind a 19 mm window open on both faces, and its electronics end in a pocket above the window (Figure 3). Its lead runs from the top of the board up to the spigot: straight up for the upper probe, and along a cross channel and the left wire channel for the lower probe (Figure 9).

**Check before moving on.** Each board lies flat in its slots in the front fin half with its parts inside the pocket; at 3.3 V the output gives a steady square wave whose frequency falls when you hold the sensing area in your hand.

### 3.2 EC electrodes (make 2)

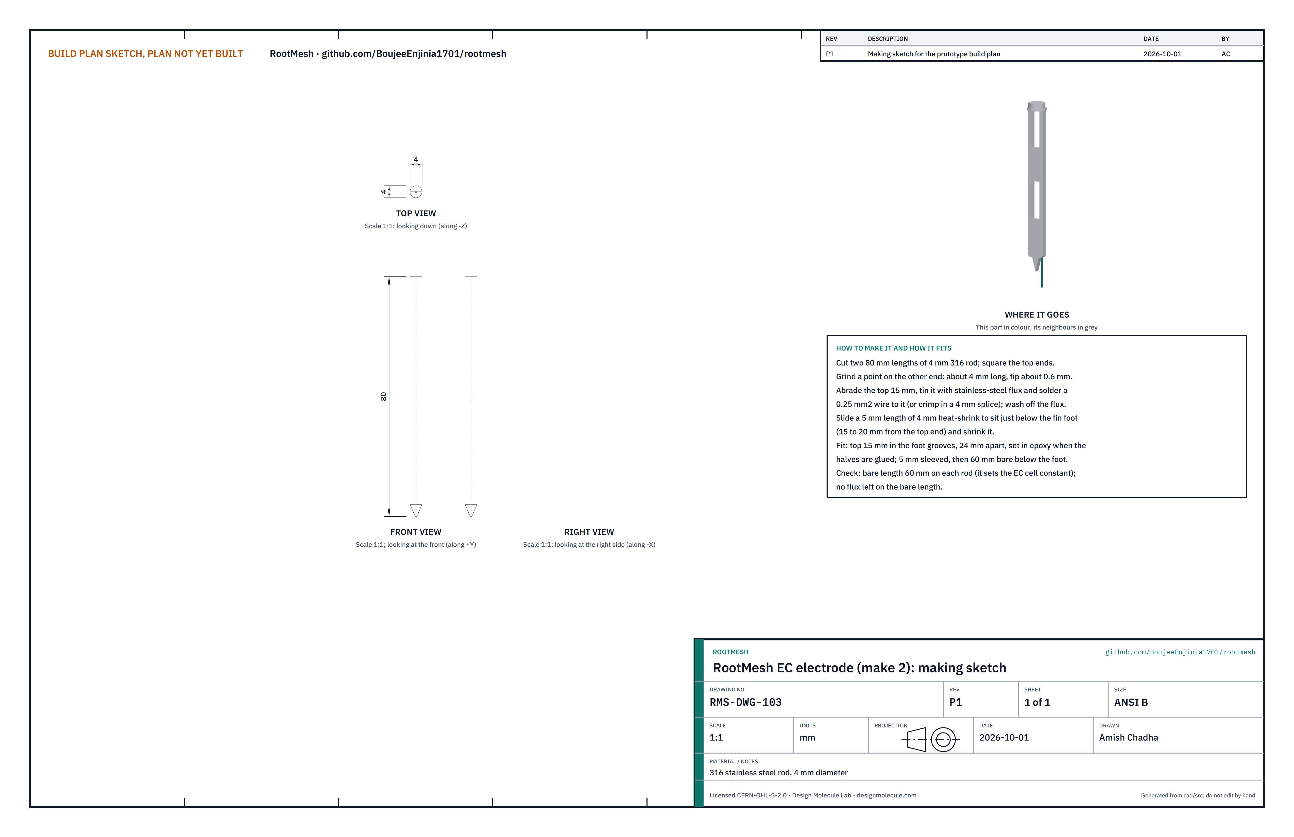
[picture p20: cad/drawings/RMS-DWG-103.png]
Figure 4. Making sketch of the EC electrode


*Figure 4. EC electrode making sketch (RMS-DWG-103).*

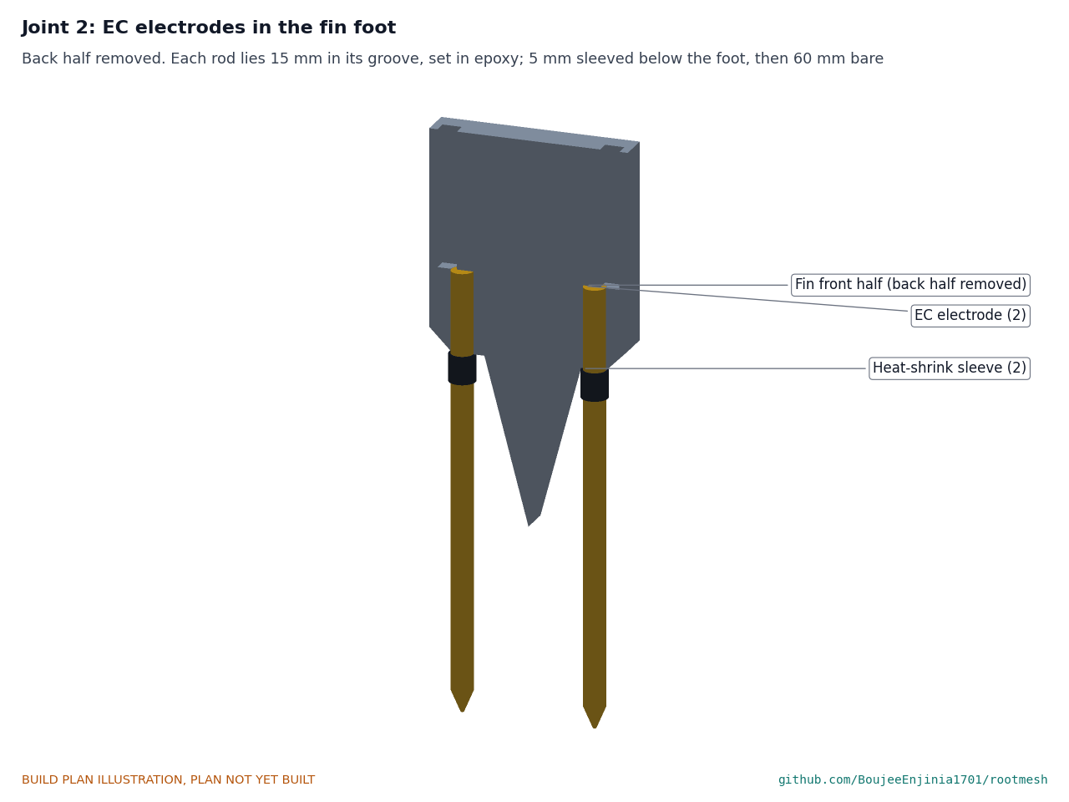
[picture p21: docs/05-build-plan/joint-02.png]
Figure 5. The electrodes in the fin foot


*Figure 5. Each electrode lies 15 mm in its groove in the fin foot; 5 mm is sleeved below the foot, then 60 mm is bare.*

**What it is and what it is made from.** One of the two steel rods below the fin that measure the soil's electrical conductivity. Type 316 stainless steel rod, 4 mm diameter.

**How to make it.**

1. Cut two 80 mm lengths of rod. Square the top ends with a file.
2. Grind the other end to a point about 4 mm long, keeping the tip on the rod's centre line.
3. Clean the top 15 mm with abrasive paper. Tin it using flux made for stainless steel and solder on a 0.25 mm² lead about 600 mm long (or crimp the lead in a 4 mm splice). Wash off all the flux.
4. Slide a 5 mm length of 4 mm heat-shrink sleeve onto the rod so it sits 15 to 20 mm from the top end, and shrink it.

**How it fits the parts next to it.** The top 15 mm of each rod lies in a 4.1 mm groove between the two fin halves, 12 mm either side of the centre line (24 mm apart), set in the epoxy that glues the halves. The sleeve sits just below the fin foot, and the 60 mm below it is bare. The fin's wedge tip sits between the two rods (Figure 5).

**Check before moving on.** The bare length is 60 mm on both rods (it sets the reading); no flux is left on the bare steel; the soldered lead holds a firm pull.

### 3.3 Temperature probe

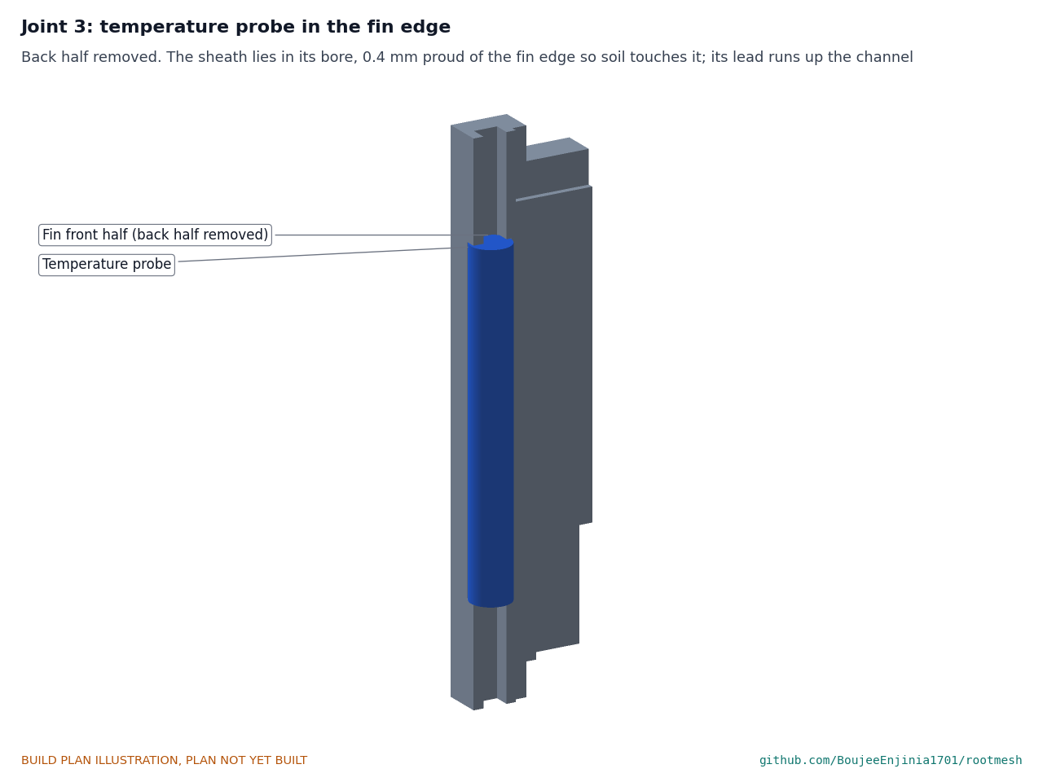
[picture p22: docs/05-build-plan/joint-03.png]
Figure 6. The temperature probe in the fin edge


*Figure 6. The probe's steel sheath lies in a bore in the right edge of the fin, 0.4 mm proud of the edge, between the two windows.*

**What it is and what it is made from.** A bought DS18B20 digital temperature sensor in a 6 mm stainless steel sheath, about 50 mm long, with a 1 m three-core lead.

**How to prepare it.** Cut the lead to about 600 mm. Strip the outer jacket from the first 300 mm next to the sheath, so the three inner wires lie flat in the wire channel; keep the inner insulation whole.

**How it fits the parts next to it.** The sheath lies in a 6.2 mm bore in the right edge of the fin, 15.4 mm from the centre line, from 200 to 250 mm deep, so its outer face stands 0.4 mm out from the fin edge and touches the soil. Its wires run up the right wire channel to the spigot. The epoxy that glues the halves fills round it.

**Check before moving on.** The sheath drops into the bore in the front half and stands just proud of the edge; it reads room temperature to within 0.5 °C of a reference thermometer.

### 3.4 Sensor fin halves (print 2: a front and a back)

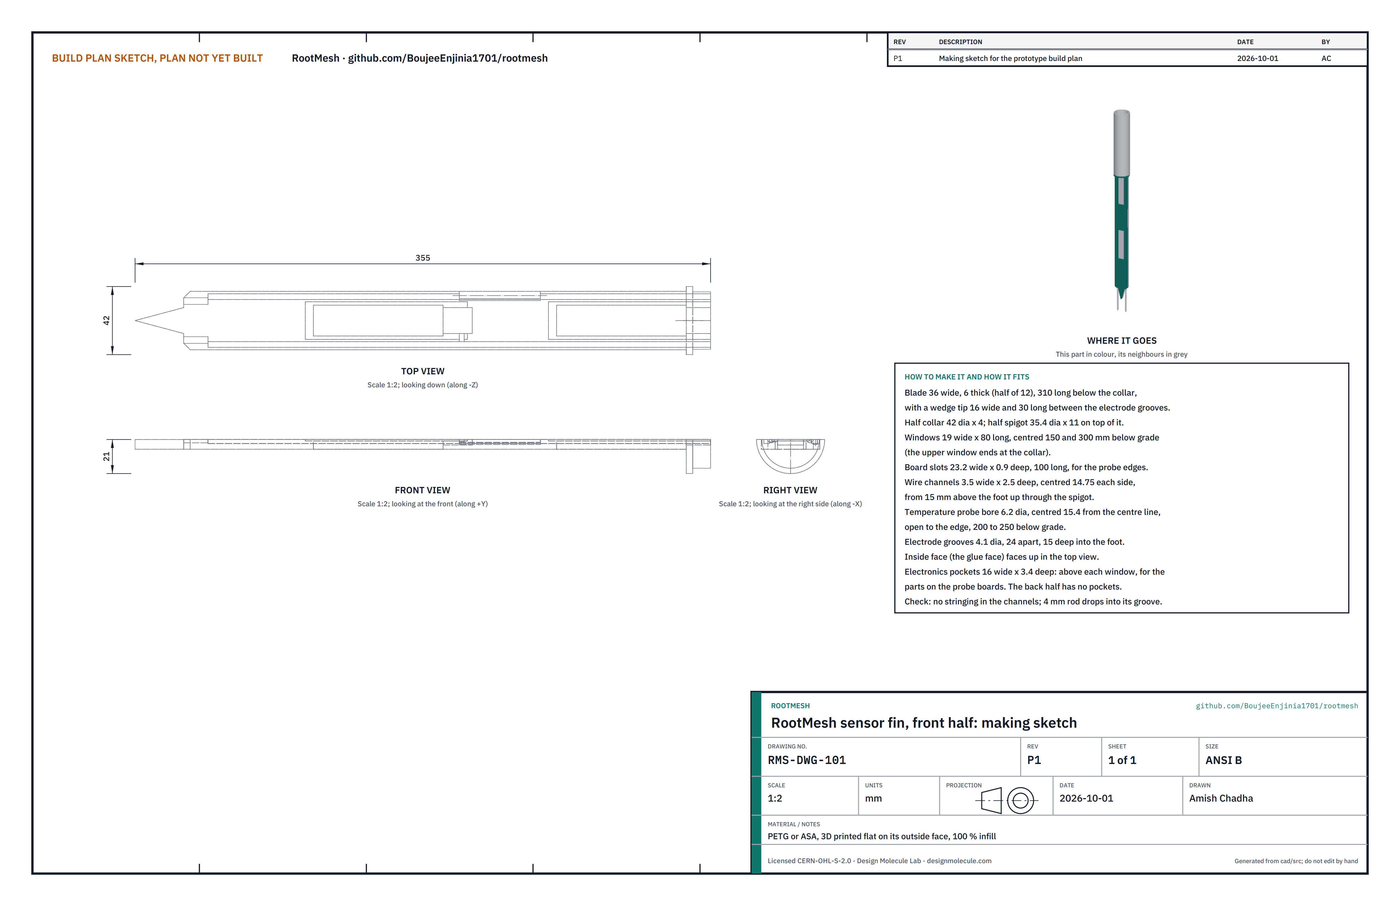
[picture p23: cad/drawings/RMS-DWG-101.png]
Figure 7. Making sketch of the front fin half


*Figure 7. Front half making sketch (RMS-DWG-101).*

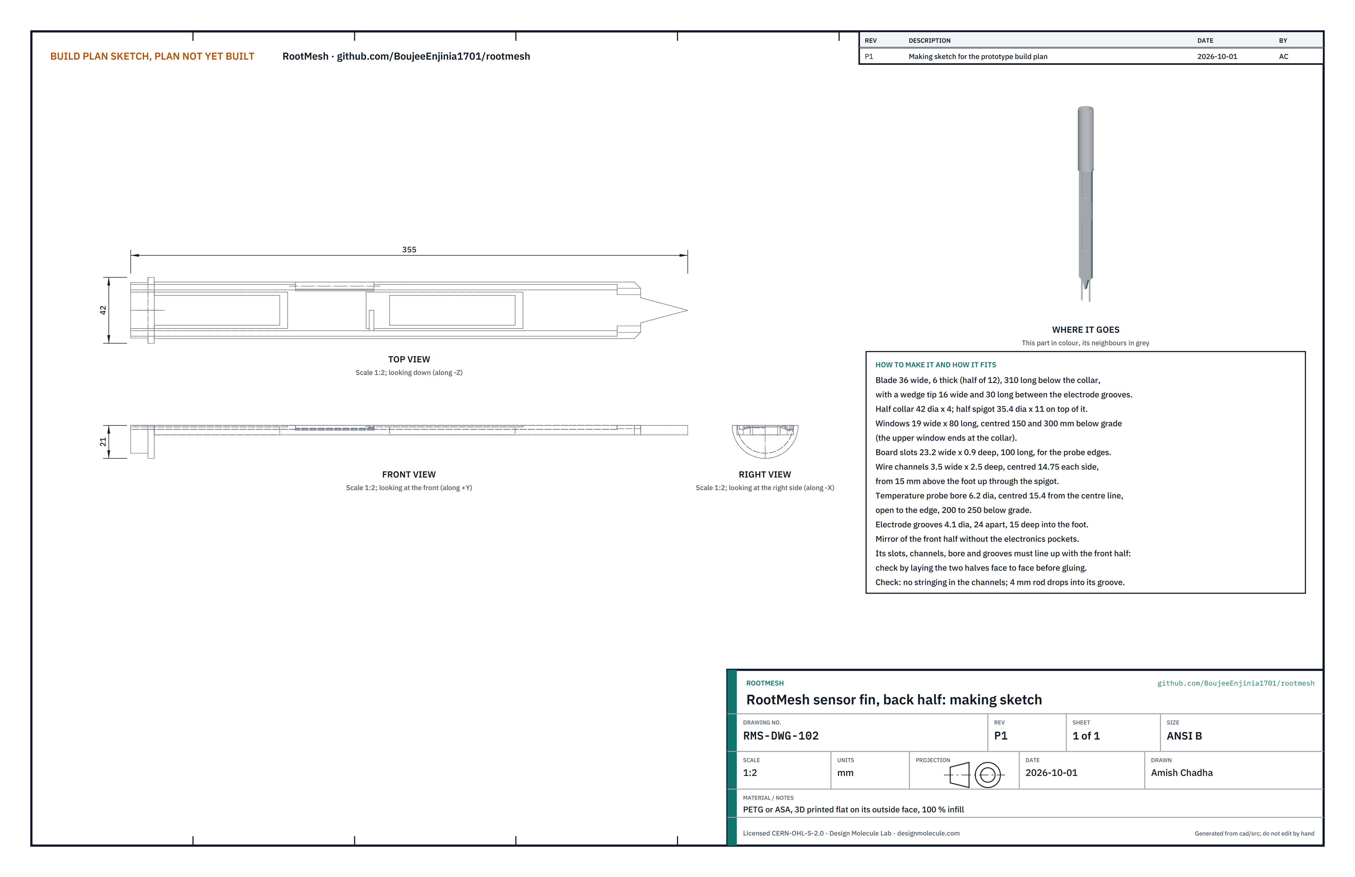
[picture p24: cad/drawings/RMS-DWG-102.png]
Figure 8. Making sketch of the back fin half


*Figure 8. Back half making sketch (RMS-DWG-102).*

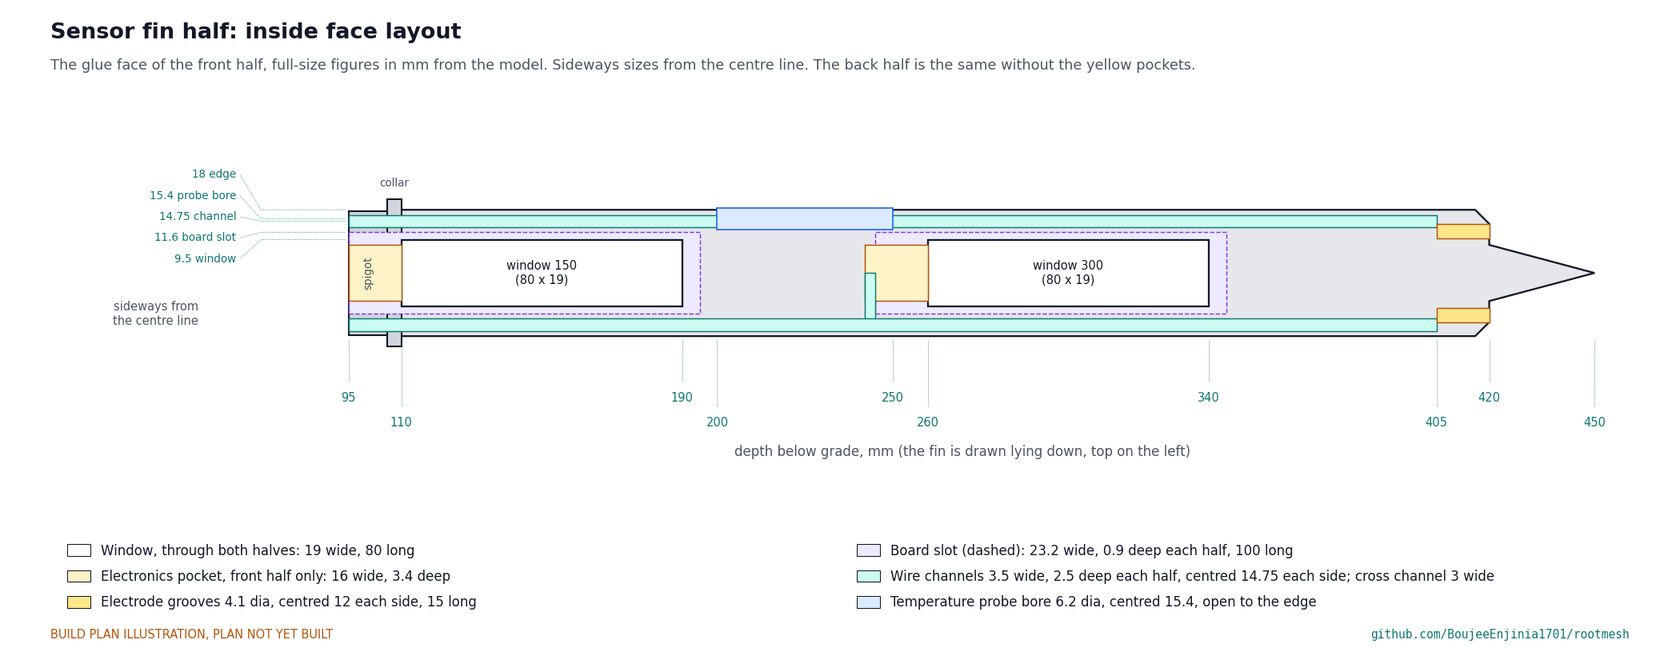
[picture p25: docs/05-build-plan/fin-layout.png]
Figure 9. The inside face of a fin half, with every cut sized


*Figure 9. The inside (glue) face of the front half, drawn lying down with the top on the left, with every cut sized from the model.*

**What it is and what it is made from.** The flat blade that is pushed into the soil and carries all the sensors. It is printed in two halves, 6 mm thick each, that are glued face to face into a blade 36 mm wide, 12 mm thick and 310 mm long, with a half collar (42 mm across, 4 mm thick) and a half spigot (35.4 mm across, 11 mm long) at the top and a wedge tip at the bottom. PETG or ASA, printed flat on its outside face at 100 % infill.

**How to make it.**

1. Print each half lying on its outside face, so the inside face with all its cuts faces up. A half is 355 mm long overall: print it on a 300 x 300 mm bed laid diagonally.
2. Clean out every slot, channel, pocket, bore and groove with a hobby knife; there must be no strings of plastic in the wire channels.
3. Check the cuts against Figure 9: two windows 19 wide and 80 long through the half, centred 150 and 300 mm deep; board slots 23.2 wide and 0.9 deep each half, 100 long; two wire channels 3.5 wide and 2.5 deep each half, centred 14.75 mm each side, from 405 mm deep up through the spigot; a cross channel from the top of the lower probe to the left channel; a 6.2 mm bore on the right edge from 200 to 250 mm deep; two 4.1 mm grooves for the electrodes, 15 mm long, in the foot. The front half also has two electronics pockets, 16 wide and 3.4 deep, above each window.
4. Lightly sand both glue faces flat on abrasive paper laid on a flat board, and wipe them with isopropyl alcohol.

**How it fits the parts next to it.** The two halves meet on their inside faces and are glued with epoxy, which also fills round the probes, electrodes and temperature probe and their wires (Figures 3, 5 and 6). The tube's bottom end sits on the collar and is glued over the spigot (Figure 11). The cell holder's legs stand on the spigot top. The channels and the upper probe's pocket open at the spigot top, where the wires leave the fin.

**Check before moving on.** Lay the two halves face to face with nothing between them: the windows, slots, channels, bore and grooves line up, and no light shows along the joint. A 4 mm rod drops into each electrode groove, and each probe board lies flat in its slots.

### 3.5 Stake tube

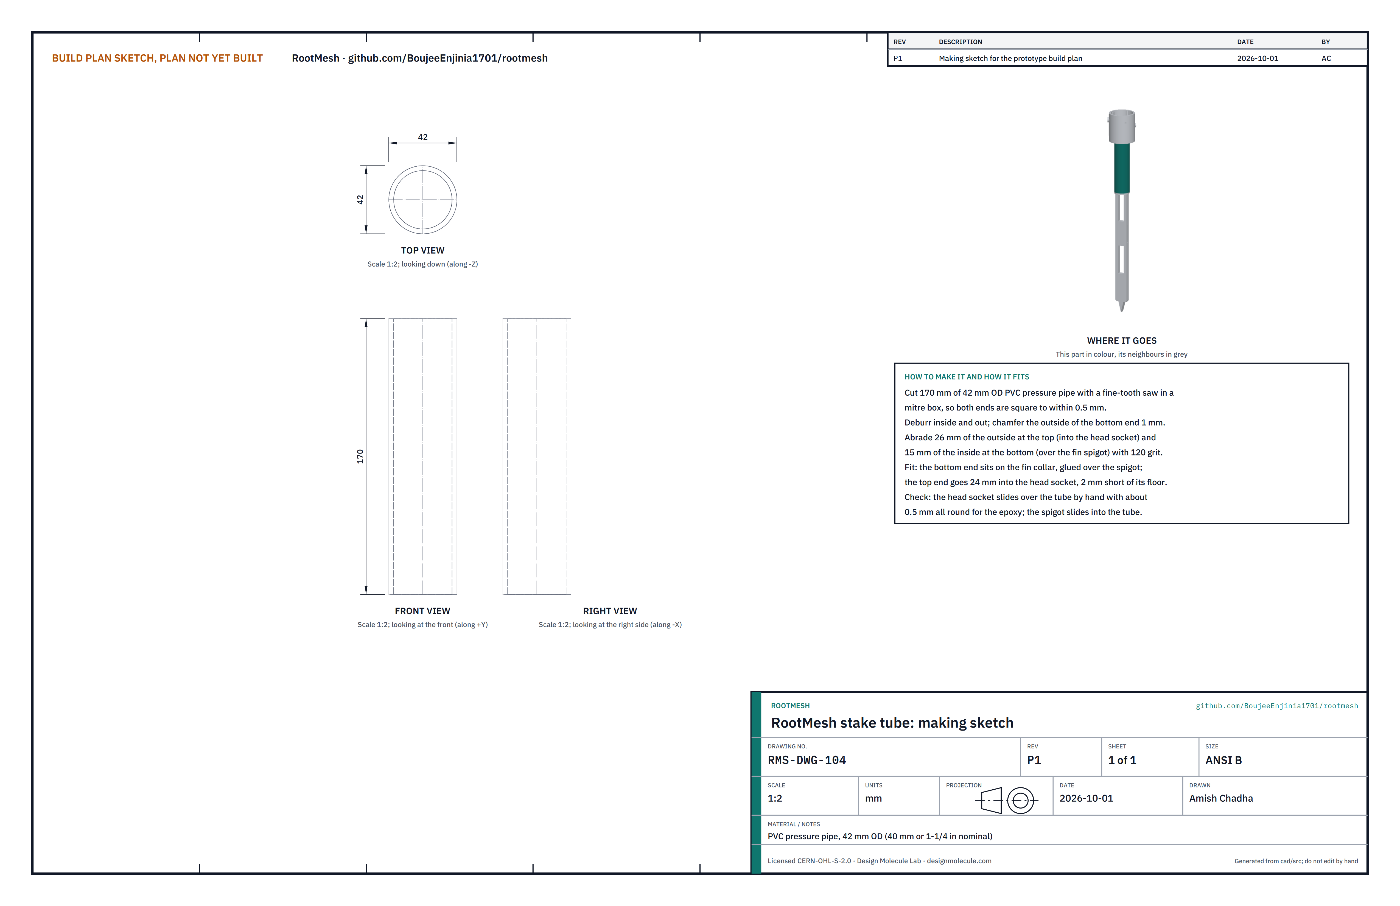
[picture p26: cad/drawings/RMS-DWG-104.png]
Figure 10. Making sketch of the stake tube


*Figure 10. Stake tube making sketch (RMS-DWG-104).*

**What it is and what it is made from.** The pipe between the fin and the head that carries the cell and the wires. PVC pressure pipe, 42 mm outside and 36 mm inside diameter (40 mm or 1-1/4 in nominal).

**How to make it.**

1. Cut 170 mm of pipe with a fine-tooth saw in a mitre box, so both ends are square to within 0.5 mm.
2. Deburr inside and out, and chamfer the outside of the bottom end 1 mm.
3. Roughen the outside of the top 26 mm and the inside of the bottom 15 mm with 120 grit paper, for the epoxy.

**How it fits the parts next to it.**

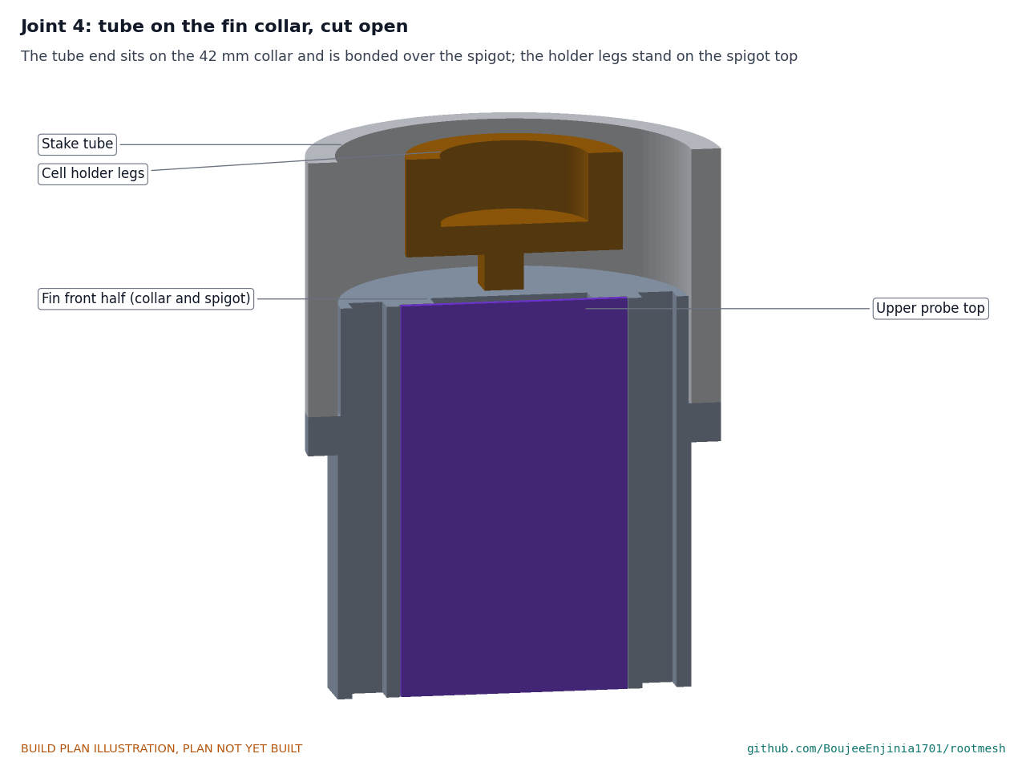
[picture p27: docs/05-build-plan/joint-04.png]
Figure 11. The tube on the fin collar, cut open


*Figure 11. The tube's bottom end sits on the 42 mm collar and is glued over the spigot; the cell holder's legs stand on the spigot top.*

The bottom end sits on the fin collar, 106 mm below the soil surface, glued over the spigot with about 0.3 mm of epoxy all round (Figure 11). The top end goes 24 mm into the head socket, 2 mm short of its floor, with about 0.5 mm of epoxy all round (Figure 14).

**Check before moving on.** The spigot slides into the tube, and the head socket slides over it, by hand, with an even gap.

### 3.6 Cell holder

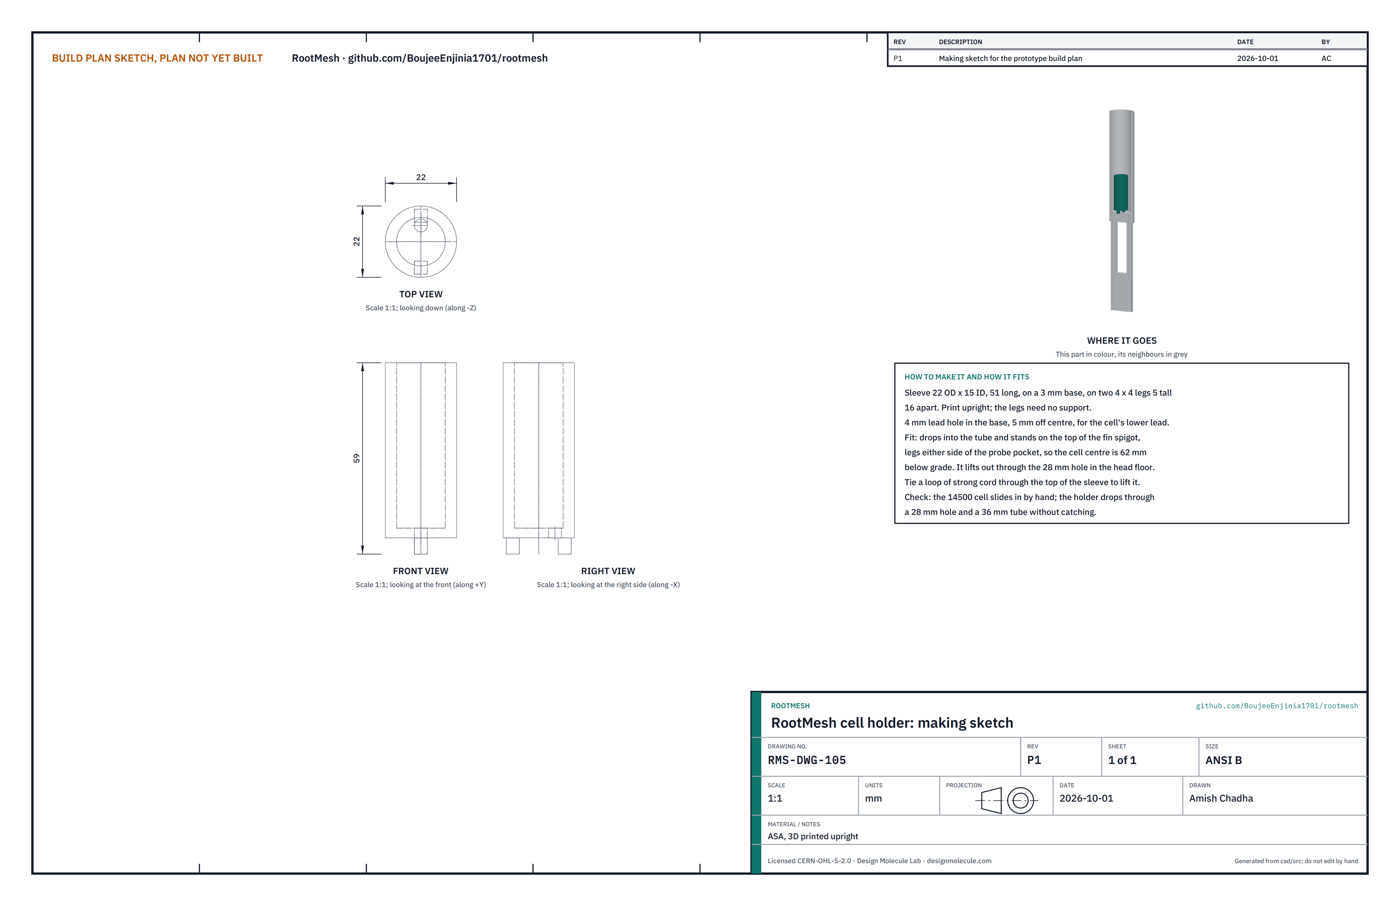
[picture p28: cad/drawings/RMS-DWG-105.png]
Figure 12. Making sketch of the cell holder


*Figure 12. Cell holder making sketch (RMS-DWG-105).*

**What it is and what it is made from.** A printed sleeve that holds the cell at the right depth inside the tube. ASA, printed upright.

**How to make it.**

1. Print the holder: a sleeve 22 mm outside and 15 mm inside diameter, 51 mm long, on a 3 mm base, standing on two legs 4 x 4 mm and 5 mm tall, 16 mm apart. The base has a 4 mm hole 5 mm off centre for the cell's lower lead.
2. Tie a loop of strong nylon cord through the top of the sleeve, long enough to reach out of the head.

**How it fits the parts next to it.** It drops down the tube and stands on the spigot top, its legs either side of the upper probe's pocket, so the cell's centre is 62 mm below the soil surface (Figure 11). The cell slides into the sleeve. The holder is 22 mm across, so it passes the 28 mm hole in the head floor and lifts out on its cord once the cap and board are out.

**Check before moving on.** The cell slides in by hand; the holder drops through a 28 mm hole and down the tube without catching.

### 3.7 Head body, with its gland, vent, status LED and inserts

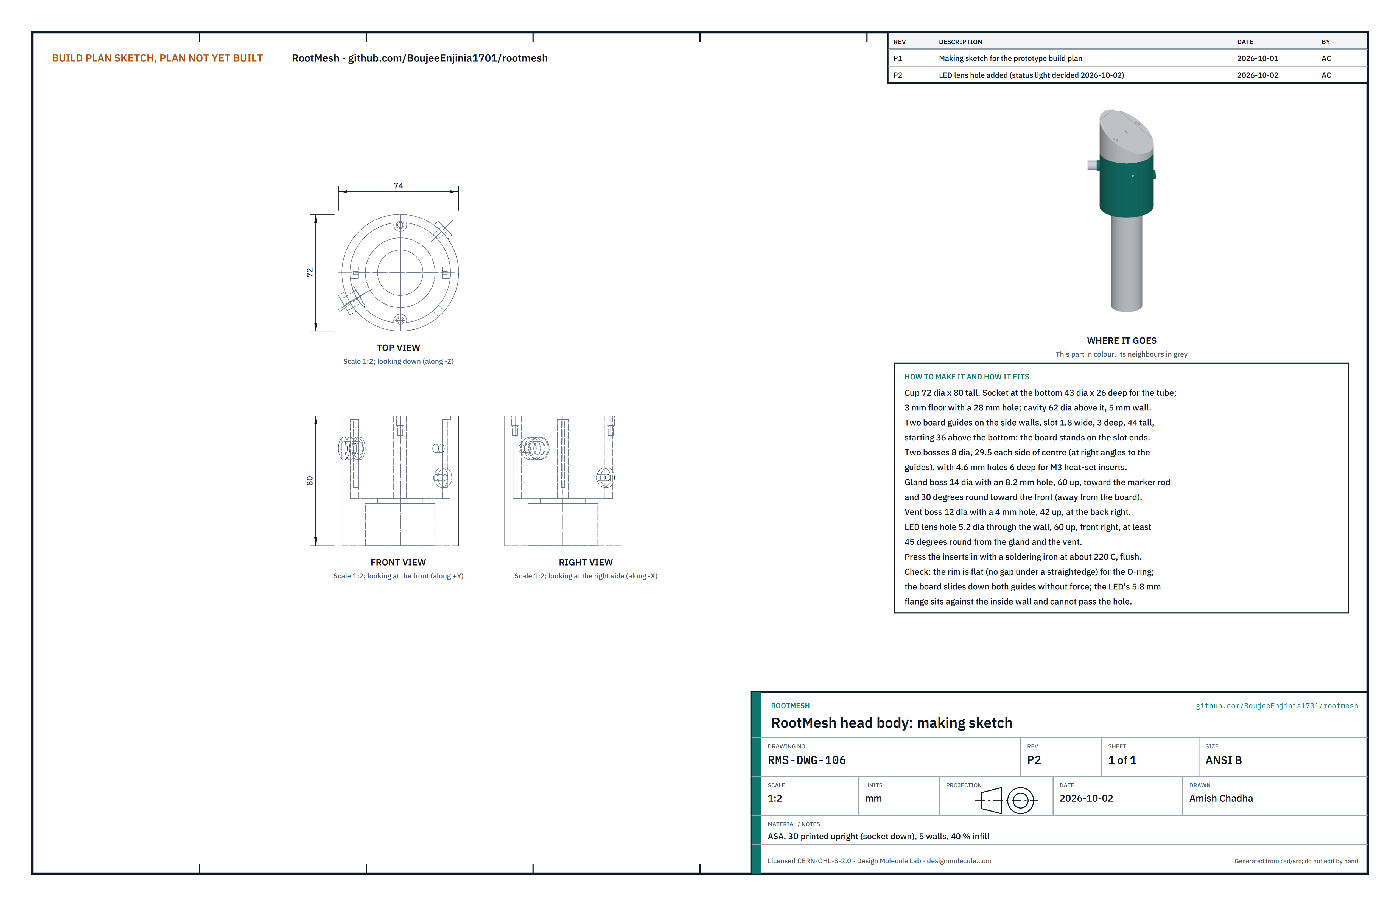
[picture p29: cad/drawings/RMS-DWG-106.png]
Figure 13. Making sketch of the head body


*Figure 13. Head body making sketch (RMS-DWG-106).*

**What it is and what it is made from.** The lower part of the head, just above the ground: a printed cup that is glued over the tube and holds the controller board. ASA, printed upright with the socket down, five walls, 40 % infill.

**How to make it.**

1. Print the body: a cup 72 mm across and 80 mm tall. At the bottom, a socket 43 mm across and 26 mm deep for the tube; above it a 3 mm floor with a 28 mm hole; above that, a cavity 62 mm across with a 5 mm wall.
2. Check the two board guides on the left and right walls: slots 1.8 mm wide and 3 mm deep, 44 mm tall, starting 36 mm above the body's bottom.
3. Check the two bosses on the front and back walls, 29.5 mm from the centre, each with a 4.6 mm hole 6 mm deep.
4. Press an M3 brass heat-set insert into each boss hole with a soldering iron at about 220 °C, until it sits flush with the rim.
5. Fit the antenna gland through the 8.2 mm hole in the gland boss, 60 mm up the body, on the left, turned 30 degrees toward the front, with its seal outside and its locknut inside; tighten the locknut by hand and a quarter turn.
6. Stick the ePTFE vent membrane on the inside of the body over the 4 mm vent hole at the back right, 42 mm up, pressing it flat round its edge.
7. Check the 5.2 mm lens hole through the wall at the front right, 60 mm up and at least 45 degrees round from the gland and the vent. Press the 5 mm green LED into it from inside until its 5.8 mm flange sits against the inside wall; the flange is larger than the hole, so the LED cannot fall out. Run a thin bead of epoxy round the flange on the inside and leave its two leads long.

**How it fits the parts next to it.**

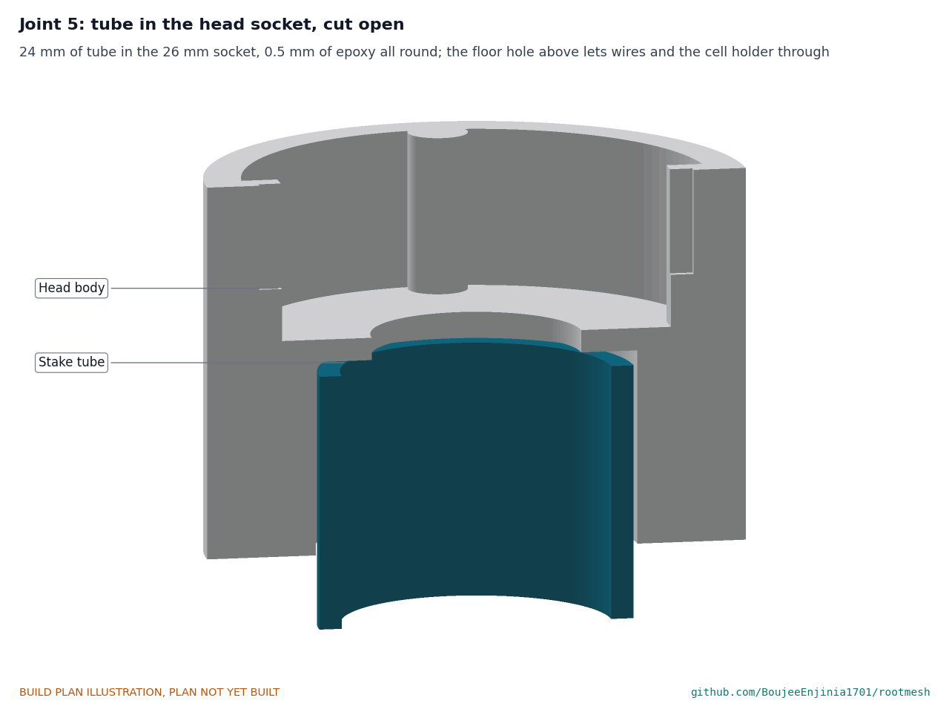
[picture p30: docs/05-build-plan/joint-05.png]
Figure 14. The tube in the head socket, cut open


*Figure 14. 24 mm of tube in the 26 mm socket, with about 0.5 mm of epoxy all round; the floor hole above lets the wires and the cell holder through.*

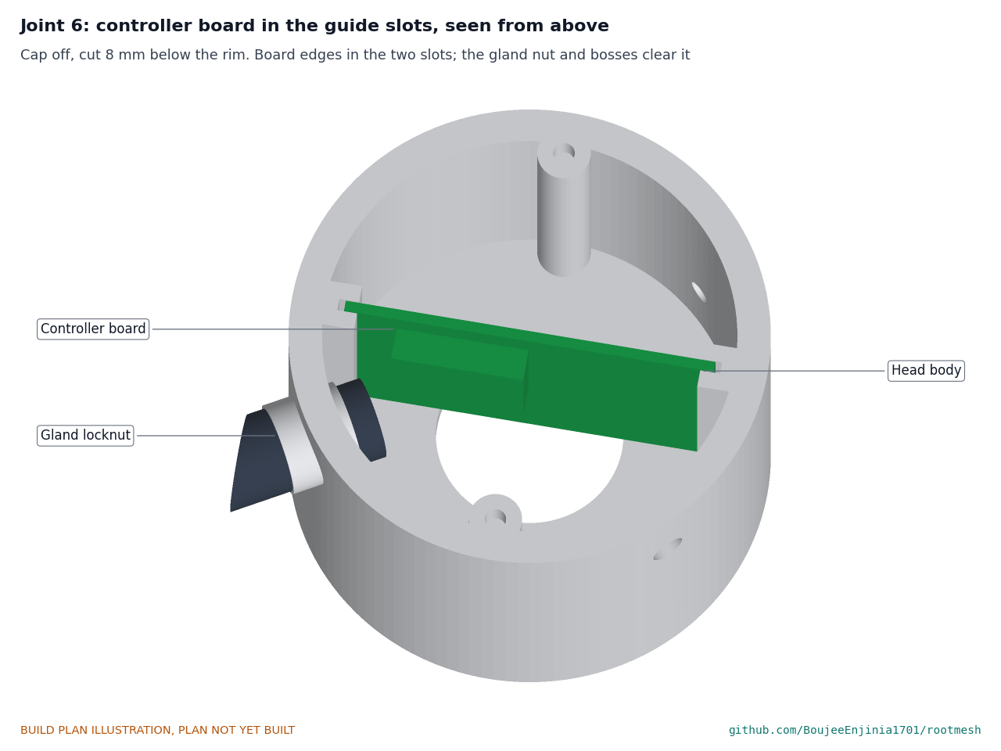
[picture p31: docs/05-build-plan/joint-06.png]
Figure 15. The board in its guide slots


*Figure 15. Seen from above with the cap off: the board's edges in the two guide slots, clear of the gland locknut and the screw bosses.*

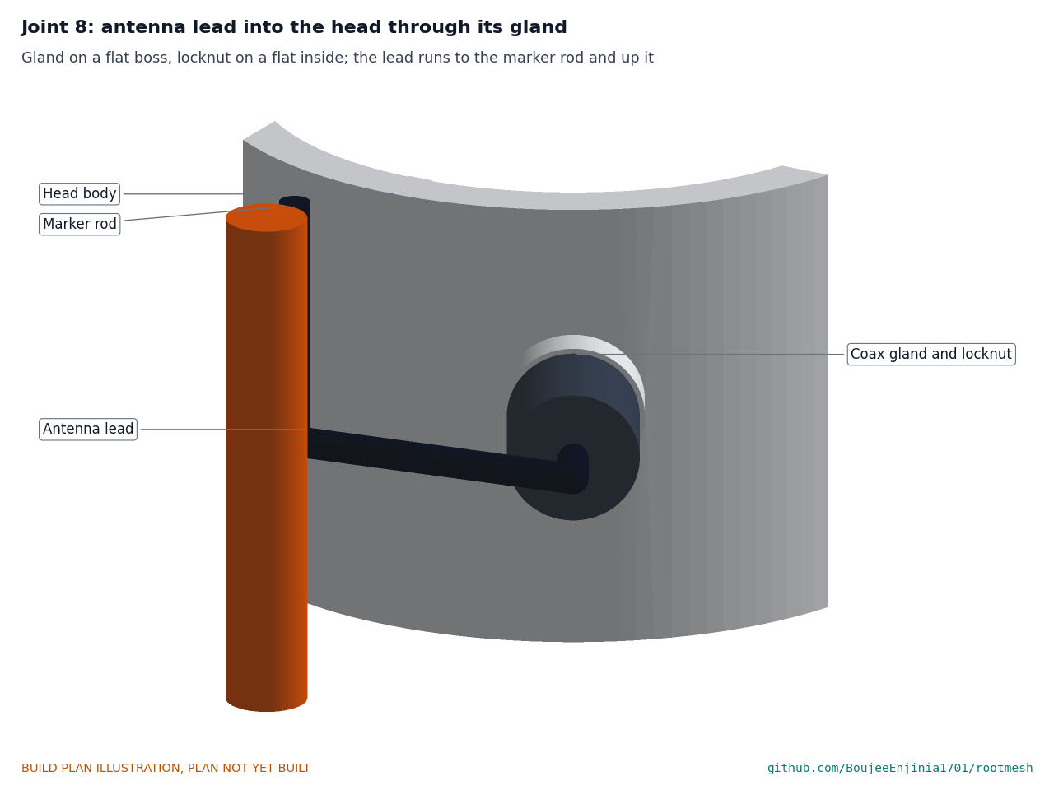
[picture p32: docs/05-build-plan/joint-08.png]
Figure 16. The antenna lead through its gland


*Figure 16. The gland on its flat boss, with its locknut on a flat inside; the lead runs to the marker rod.*

The socket is glued over the top of the tube (Figure 14). The board stands in the guides (Figure 15). The cap sits on the rim, its O-ring sealing on the rim face, held by two screws into the inserts (Figure 19). The gland faces the marker rod (Figure 16).

**Check before moving on.** The rim is flat (no gap under a straightedge); the board slides down both guides without force; the inserts are square and flush.

### 3.8 Controller board (bought modules)

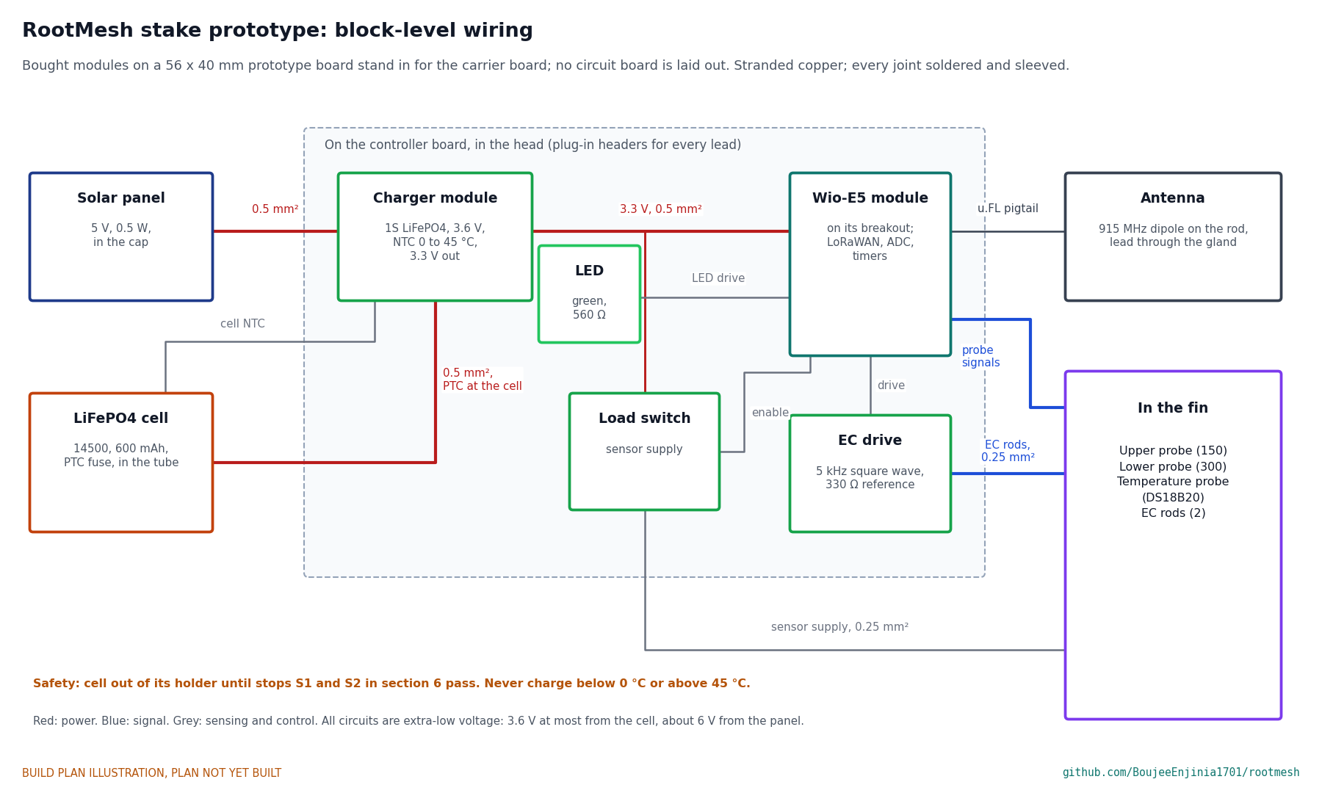
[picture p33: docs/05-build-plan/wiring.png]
Figure 17. Block-level wiring


*Figure 17. Block-level wiring with wire sizes. No circuit board is laid out at this stage; bought modules on a prototype board stand in for the carrier board.*

The carrier board in the bill of materials is a custom board, which is TRL 4 work. For this prototype, lay out bought modules on a 56 x 40 mm prototype board (perforated board, 1.6 mm thick) to this specification:

*Table 2. Modules that stand in for the carrier board.*

| Module | What to buy |
| --- | --- |
| Radio and controller | STM32WLE5-class LoRaWAN module (Seeed Wio-E5 or similar) on its maker's small breakout, set to the US915 band plan (902 to 928 MHz) |
| Charger | Single-cell lithium iron phosphate solar charger (CN3058E class), charge voltage 3.6 V, with a temperature input that stops charging below 0 °C and above 45 °C, and a 3.3 V output or a 3.3 V regulator after it |
| Load switch | A small high-side switch that the controller turns on to power the sensors for about 1 s per reading |
| EC drive | Two controller pins driving the electrodes through a 330 Ω reference resistor, with both sides of the resistor wired to analog inputs |
| Status light | One 560 Ω, 0.25 W axial resistor in series with the green LED, on one controller pin: about 2 mA when lit. The controller blinks it once for 0.1 s after each uplink and three times when a magnet or button wakes it, and at no other time |

Wire it like this, with stranded copper, every joint soldered and sleeved, and a plug-in header for each lead that leaves the board:

1. Panel lead (from the cap) to the charger input: 0.5 mm².
2. Cell holder leads, through the cell's fuse, to the charger battery terminals: 0.5 mm².
3. The cell's temperature sensor to the charger's temperature input: 0.25 mm², twisted.
4. Charger 3.3 V output to the controller and to the load switch: 0.5 mm².
5. Load switch output to the supply wire of each probe and of the temperature probe: 0.25 mm².
6. Probe outputs and the temperature probe's data wire to controller pins: 0.25 mm².
7. Electrode leads to the EC drive: 0.25 mm².
8. Controller to the antenna: the u.FL pigtail to the gland, then the lead through the gland.
9. Controller pin to the 560 Ω resistor on the board, then a pair of 0.25 mm² leads from the resistor and the 3.3 V rail to the LED in the head wall, through a plug-in header.

Check that the charger's temperature window really is 0 to 45 °C in its datasheet before buying: some chargers of this class fix a different window.

**Check before moving on.** Every wire continues end to end; with no cell fitted, the battery terminals and the 3.3 V rail read open to ground; every lead and header is labelled.

### 3.9 Head cap, with its panel and O-ring

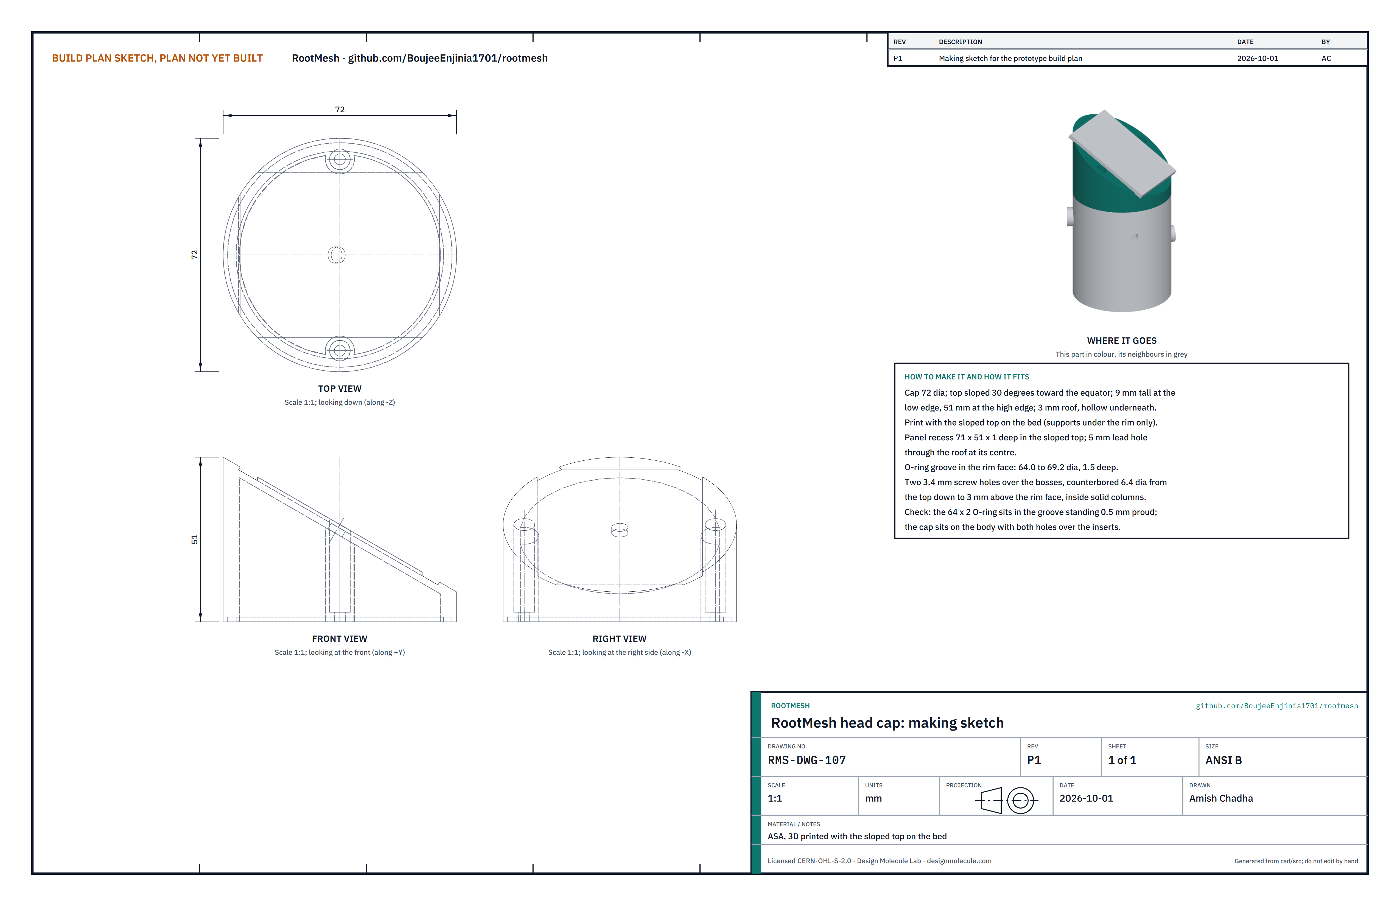
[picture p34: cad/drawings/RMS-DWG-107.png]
Figure 18. Making sketch of the head cap


*Figure 18. Head cap making sketch (RMS-DWG-107).*

**What it is and what it is made from.** The top of the head: a printed cap sloped 30 degrees toward the equator, carrying the solar panel and sealing the head. ASA, printed with the sloped top on the bed and supports under the rim only.

**How to make it.**

1. Print the cap: 72 mm across, 9 mm tall at its low edge and 51 mm at its high edge, with a 3 mm roof and hollow underneath.
2. Check the panel recess, 71 x 51 mm and 1 mm deep, the 5 mm lead hole at its centre, the O-ring groove in the rim face (64.0 to 69.2 mm across, 1.5 mm deep), and the two 3.4 mm screw holes over the bosses, counterbored 6.4 mm from the top down to 3 mm above the rim face.
3. Pass the panel's lead through the hole. Run a bead of clear outdoor sealant round the recess and over the hole, press the panel in, wipe off the excess and let it cure for a day.
4. Lay the 64 x 2 mm O-ring in its groove.

**How it fits the parts next to it.**

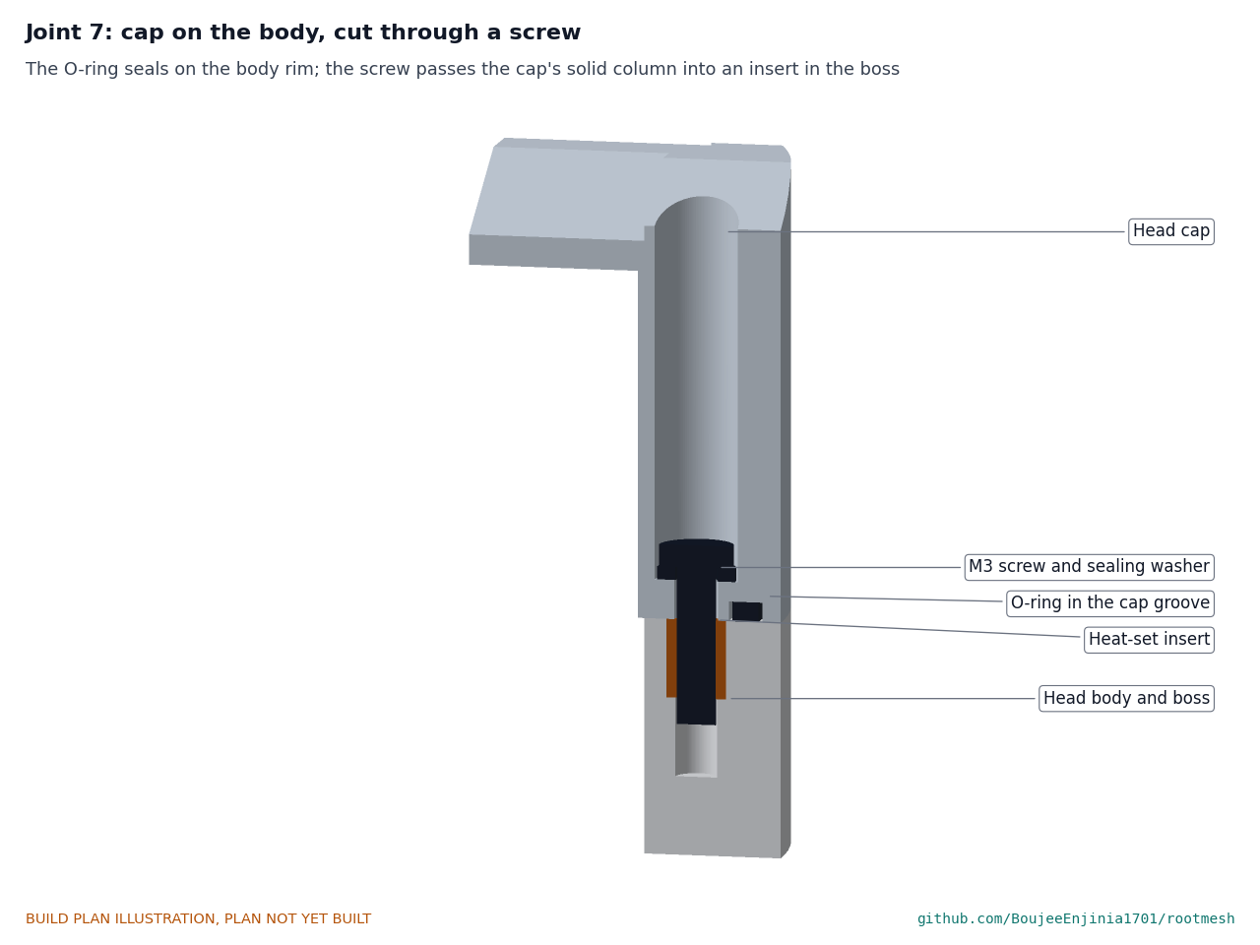
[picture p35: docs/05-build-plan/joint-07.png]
Figure 19. The cap on the body, cut through a screw


*Figure 19. The O-ring seals on the body rim; each screw passes through a solid column in the cap into an insert in a body boss.*

The cap sits on the body rim with the O-ring between them. Two M3 x 12 stainless button-head screws, each with an EPDM sealing washer under its head, pass through the cap into the inserts and are tightened snug, enough to close the gap evenly but not to crush the O-ring flat (Figure 19). The panel faces the equator.

**Check before moving on.** The O-ring stands about 0.5 mm out of its groove; the panel is bonded all round with no gap at its edge.

### 3.10 Antenna clips (print 2)

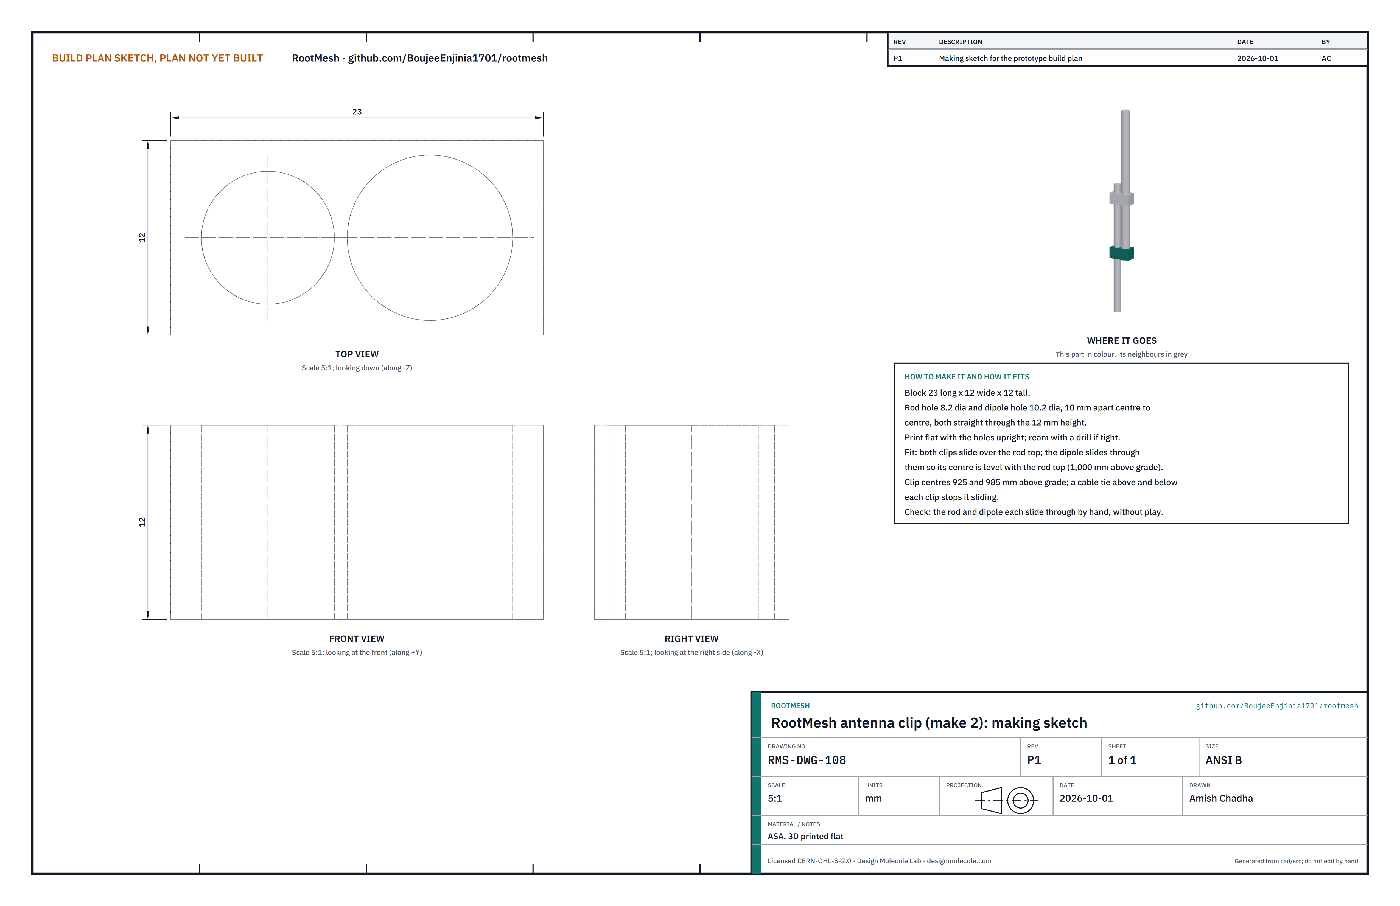
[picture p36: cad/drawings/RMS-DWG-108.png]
Figure 20. Making sketch of the antenna clip


*Figure 20. Antenna clip making sketch (RMS-DWG-108).*

**What it is and what it is made from.** A small printed block that holds the dipole beside the marker rod. ASA, printed flat.

**How to make it.** Print two blocks 23 x 12 x 12 mm, each with an 8.2 mm hole for the rod and a 10.2 mm hole for the dipole, 10 mm apart centre to centre, straight through the 12 mm height. Ream the holes with a drill if tight.

**How it fits the parts next to it.**

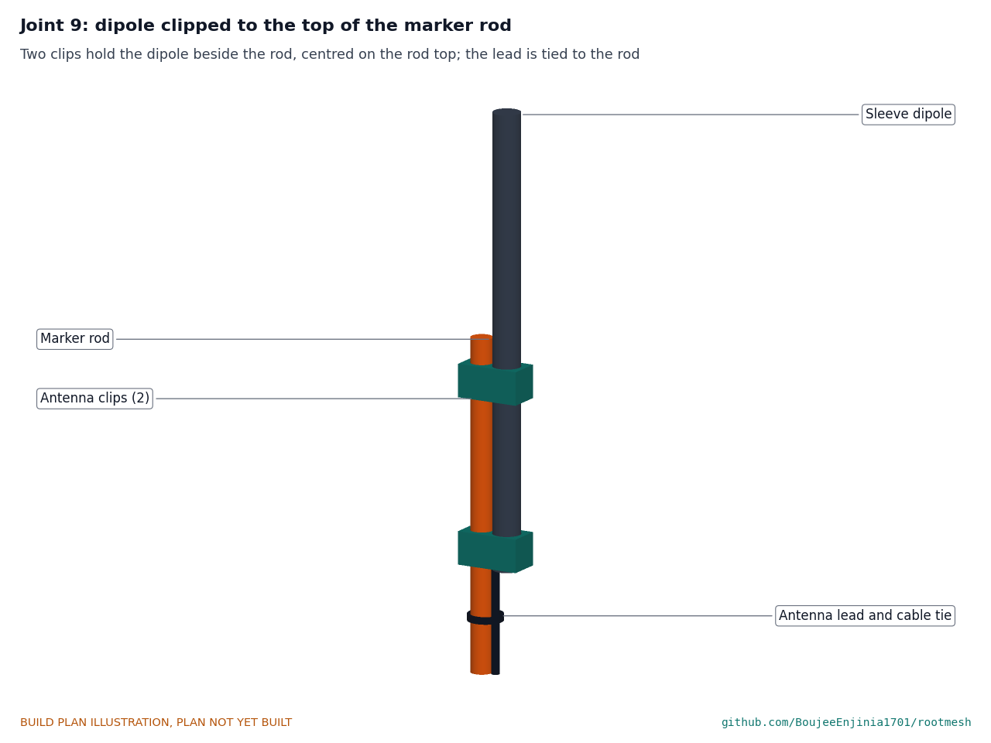
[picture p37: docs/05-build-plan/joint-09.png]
Figure 21. The dipole clipped to the rod


*Figure 21. Two clips hold the dipole beside the top of the rod; the lead is tied to the rod below them.*

Both clips slide over the rod top, centred 925 and 985 mm above the soil surface; the dipole slides down through them until its centre is level with the rod top, 1,000 mm above the soil. A cable tie above and below each clip stops it sliding.

**Check before moving on.** The rod and the dipole each slide through by hand without play.

### 3.11 Slot tool

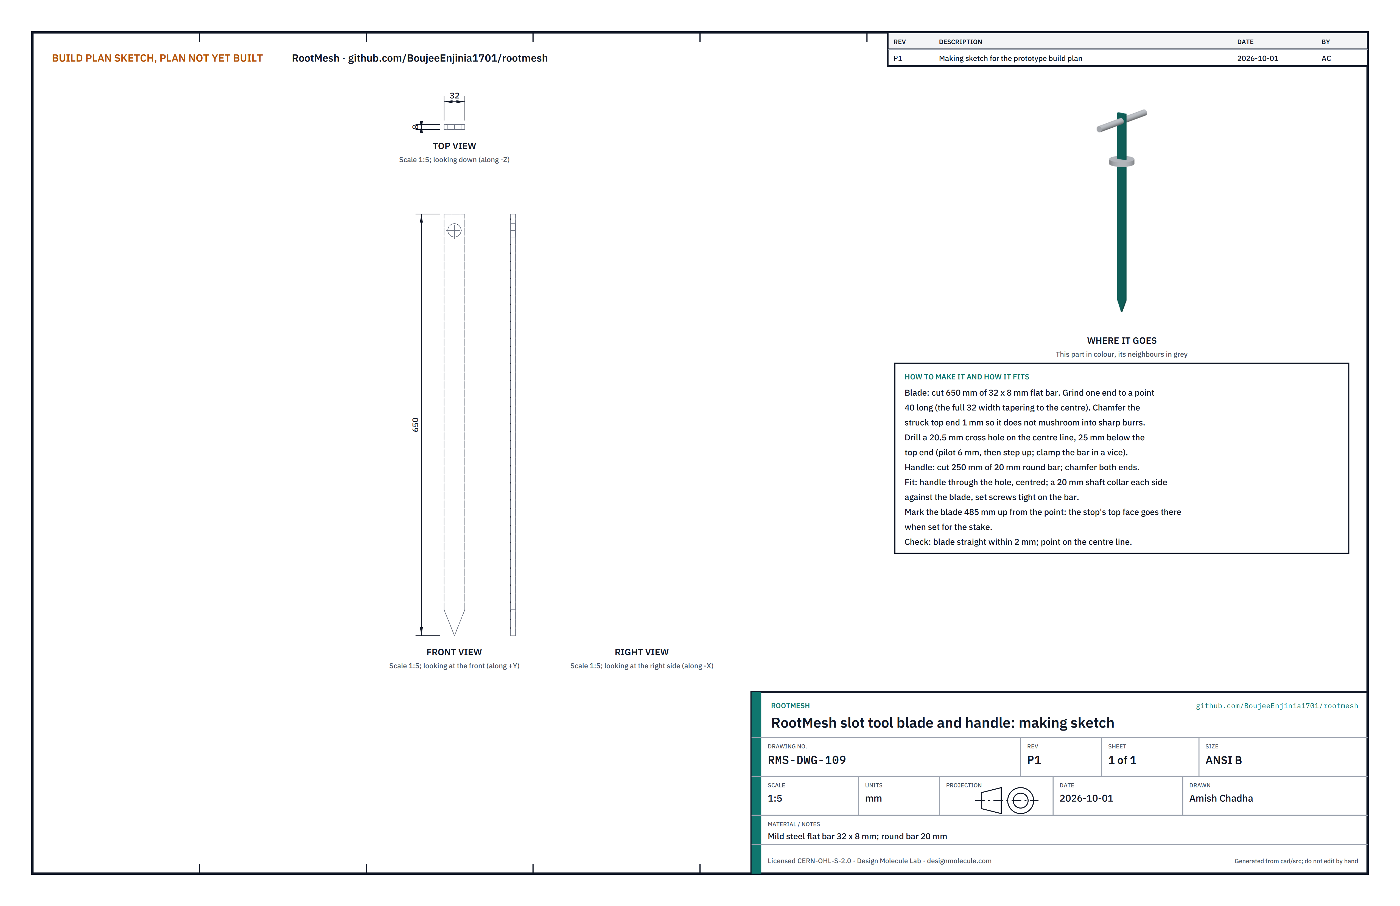
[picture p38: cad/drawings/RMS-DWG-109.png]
Figure 22. Making sketch of the slot tool blade and handle


*Figure 22. Blade and handle making sketch (RMS-DWG-109).*

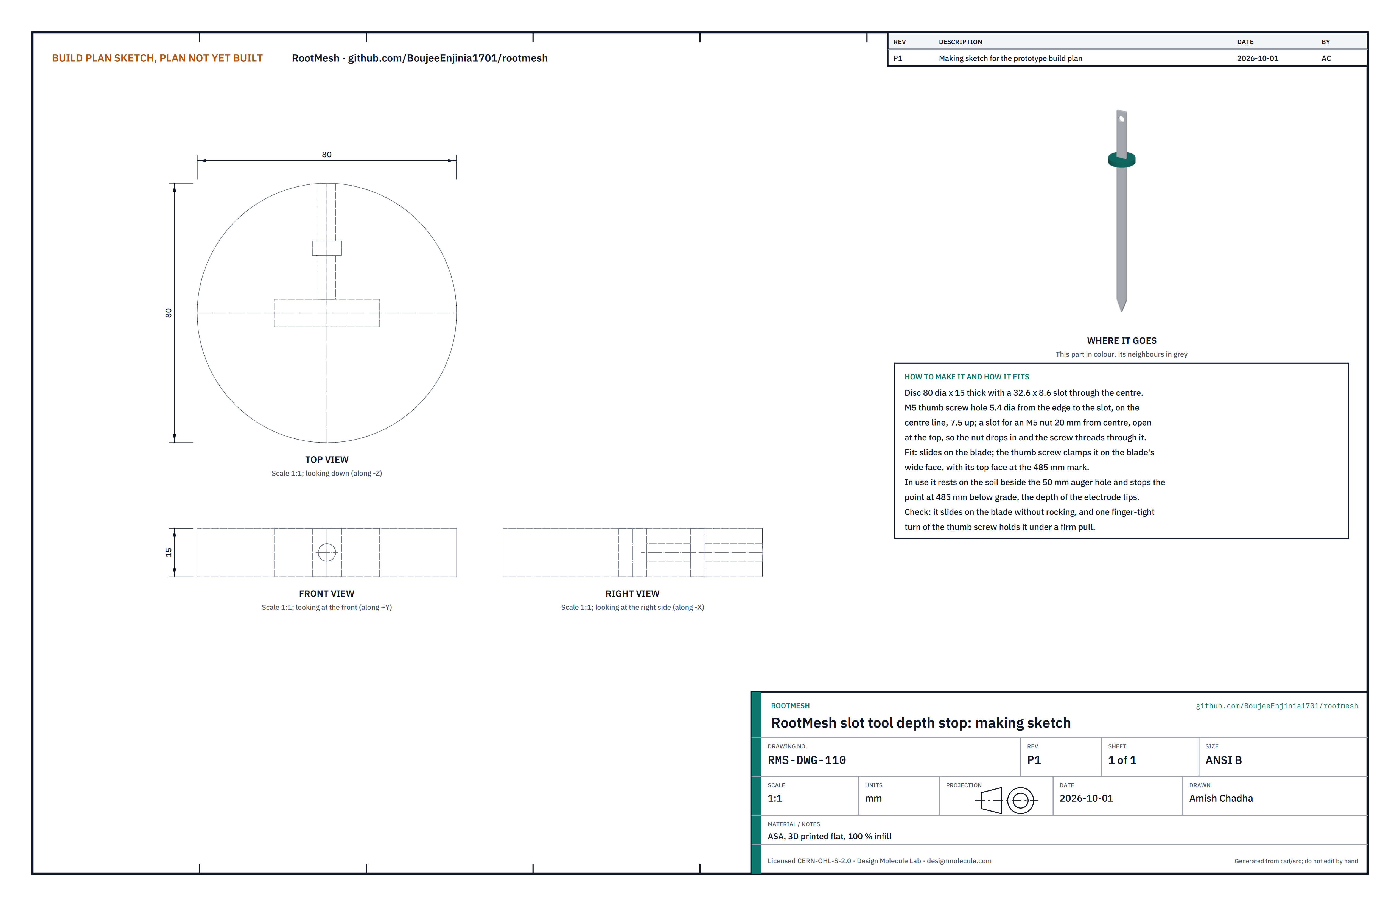
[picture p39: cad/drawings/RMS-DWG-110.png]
Figure 23. Making sketch of the depth stop


*Figure 23. Depth stop making sketch (RMS-DWG-110).*

**What it is and what it is made from.** A steel blade, the same shape as the fin but slightly thinner, that is driven down the auger hole with a mallet and pulled out, so the fin only has to widen a slot. Mild steel flat bar 32 x 8 mm for the blade; 20 mm round bar for the handle; two 20 mm bore shaft collars; a printed ASA depth stop with an M5 thumb screw and nut.

**How to make it.**

1. Blade: cut 650 mm of flat bar. Grind one end to a point 40 mm long, the full 32 mm width tapering to the centre. Chamfer the other end (the struck end) 1 mm.
2. Clamp the blade in a vice and drill a 20.5 mm cross hole on its centre line, 25 mm below the struck end: pilot 6 mm, then step up.
3. Handle: cut 250 mm of 20 mm round bar and chamfer both ends.
4. Depth stop: print a disc 80 mm across and 15 mm thick with a 32.6 x 8.6 mm slot through its centre, a 5.4 mm hole from its edge to the slot, and a slot for an M5 nut 20 mm from the centre, open at the top.
5. Mark the blade 485 mm up from the point with a paint pen.

**How it fits the parts next to it.**

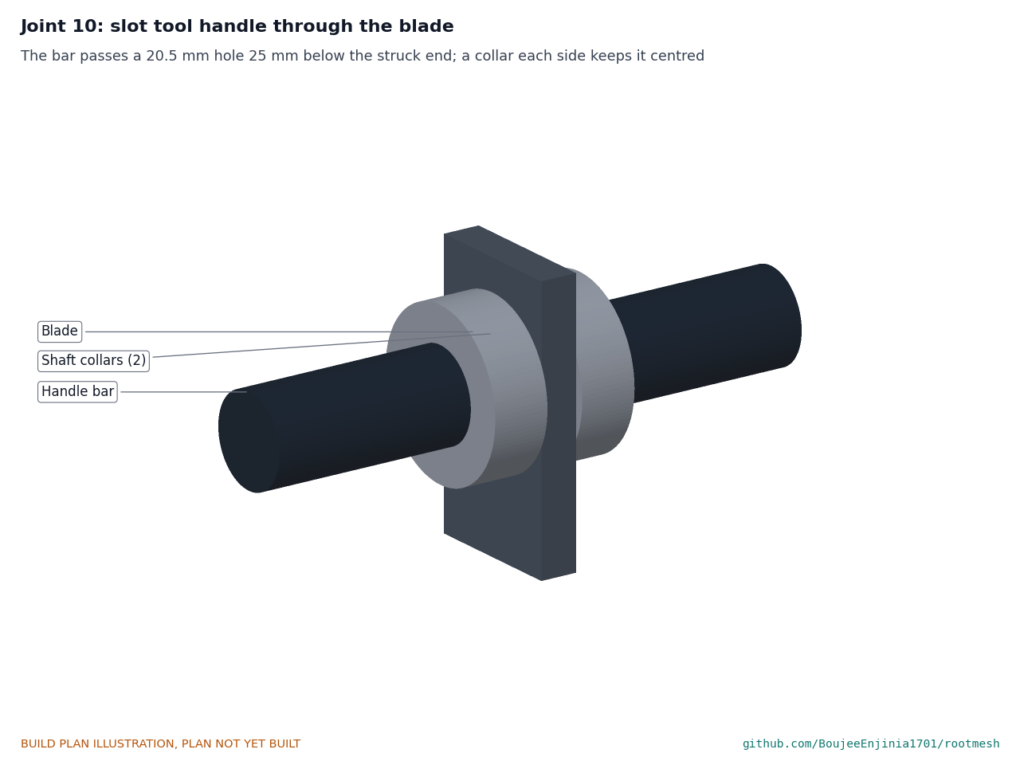
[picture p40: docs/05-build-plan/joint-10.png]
Figure 24. The handle through the blade


*Figure 24. The bar passes the cross hole; a collar each side keeps it centred.*

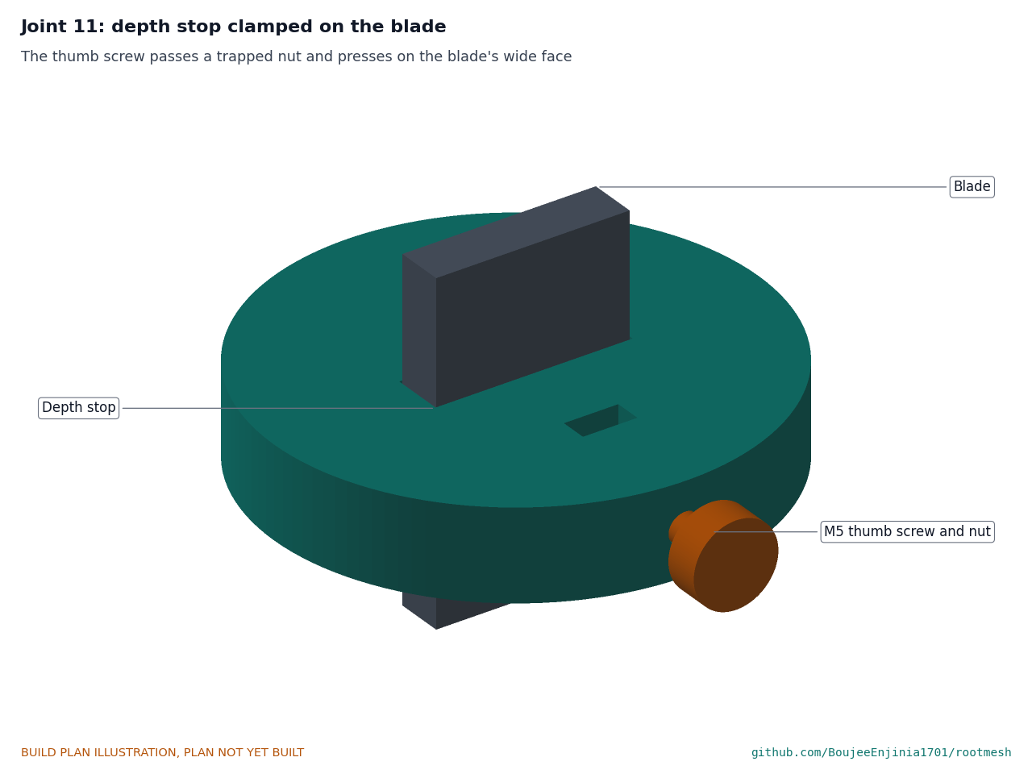
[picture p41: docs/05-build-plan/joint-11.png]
Figure 25. The depth stop on the blade


*Figure 25. The thumb screw passes the trapped nut and presses on the blade's wide face.*

The handle passes through the cross hole, centred, with a shaft collar against each face of the blade, set screws tight on the bar (Figure 24). The depth stop slides up the blade from the point until its top face is at the 485 mm mark; the M5 nut drops into its slot and the thumb screw, through the nut, clamps the stop on the blade's wide face (Figure 25). In use the stop rests on the soil beside the auger hole and stops the point 485 mm deep, level with the electrode tips.

**Check before moving on.** The blade is straight within 2 mm and the point is on its centre line; the handle does not slide in the collars; one finger-tight turn of the thumb screw holds the stop under a firm pull.

### 3.12 Bought components

Buy to specification, not brand. Line numbers are those of the bill of materials.

- **Solar panel (line 1).** 5 V, 0.5 W monocrystalline, about 70 x 50 mm, epoxy or PET laminate, with its lead on the back near the centre.
- **Controller (line 3).** The modules of Table 2 and a 56 x 40 mm prototype board (line 16).
- **Antenna (line 4).** Half-wave sleeve dipole for 915 MHz, about 164 mm long and 10 mm across, with 1.2 m of RG174 lead and a u.FL to SMA pigtail.
- **Cell (line 5).** 14500 size lithium iron phosphate cell, 3.2 V, 600 mAh, of the IFR14500EC class, whose datasheet rates discharge from -20 to +60 °C and charge from 0 to +60 °C (the charger still stops charging above 45 °C), with a resettable (PTC) fuse and leads fitted.
- **Gateway (line 13).** Indoor eight-channel LoRaWAN gateway, US915 version, with its own antenna, Wi-Fi link and USB supply, joined to The Things Network. It is not part of the stake and stays indoors.
- **Pipe (line 6).** 42 mm outside diameter PVC pressure pipe, 170 mm.
- **Moisture probes (line 8).** Two capacitive soil moisture boards, version 1.2 class, and two TLC555 timers.
- **Electrode rod (line 9).** 4 mm 316 stainless steel rod, 160 mm.
- **Temperature probe (line 10).** DS18B20 in a 6 mm stainless sheath with a 1 m lead.
- **Marker rod and flag (line 11).** 8 mm fibreglass rod, 1.2 m, with a high-visibility flag; four cable ties.
- **Seals (line 12).** One 64 x 2 mm nitrile or EPDM O-ring; one M8 IP68 cable gland for 2 to 4 mm cable; an adhesive ePTFE vent membrane about 10 mm across; a desiccant sachet; two-part epoxy for potting.
- **Fixings and bonding (line 16).** Two M3 brass heat-set inserts (short, for a 4.6 mm hole); two M3 x 12 stainless button-head screws and two EPDM sealing washers; structural two-part epoxy; 4 mm heat-shrink sleeve.
- **Status LED and resistor (line 17).** One 5 mm green diffused LED with a 5.8 mm flange, and one 560 Ω, 0.25 W axial resistor.
- **Slot tool (line 15).** 650 mm of 32 x 8 mm mild steel flat bar; 250 mm of 20 mm mild steel round bar; two 20 mm bore shaft collars with set screws; an M5 thumb screw about 40 mm long and an M5 nut.

## 4. Putting it together

In each picture the parts already fitted are grey and the part being fitted is in colour, with an arrow showing the way it goes in. Steps 1 to 11 are done on the bench; steps 12 to 16 install the stake in a trial bed of soil, at least 600 mm deep.

### Step 1: probes into the front fin half

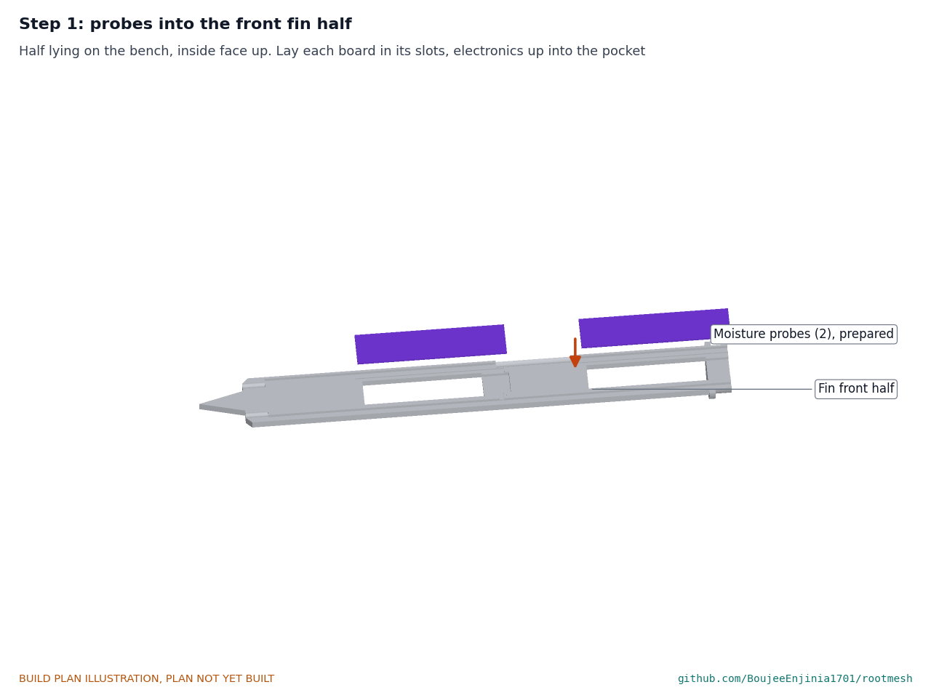
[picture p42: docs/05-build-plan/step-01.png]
Step 1


Lay the front half on the bench, inside face up. Lay each probe board in its slots with its parts up in the pocket and its lead in its channel: the upper probe's lead straight out of the spigot top, the lower probe's lead along the cross channel and up the left channel.

### Step 2: electrodes and temperature probe into the front half

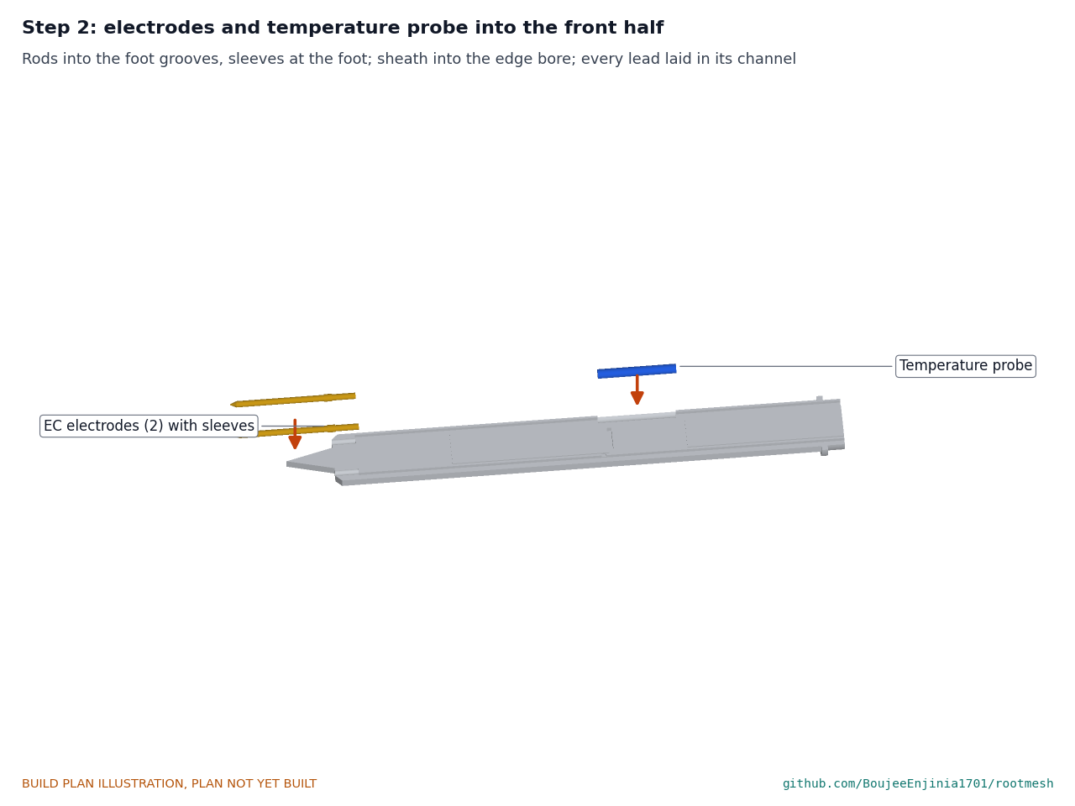
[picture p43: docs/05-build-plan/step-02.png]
Step 2


Lay each electrode in its groove with its sleeve against the foot and its lead in the channel on its side. Lay the temperature probe's sheath in its bore and its wires in the right channel. Tape the leads together where they leave the spigot.

### Step 3: glue on the back half

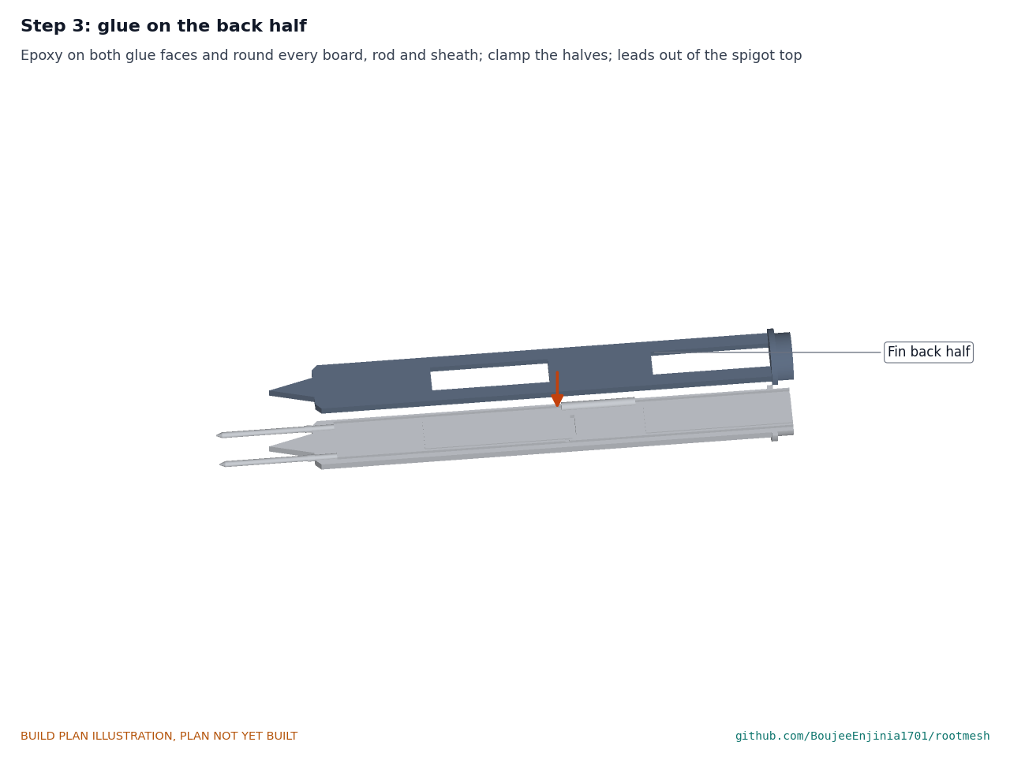
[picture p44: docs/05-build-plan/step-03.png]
Step 3


Mix enough slow-setting epoxy for the whole fin. Fill every channel and pocket round the wires, coat both glue faces, press the back half on, and clamp the halves every 50 mm between two straight battens. Wipe the excess from the windows, the edges and the bare electrodes. Let it cure fully. **Hold point:** each lead still continues end to end and none is shorted to another.

### Step 4: tube onto the fin spigot

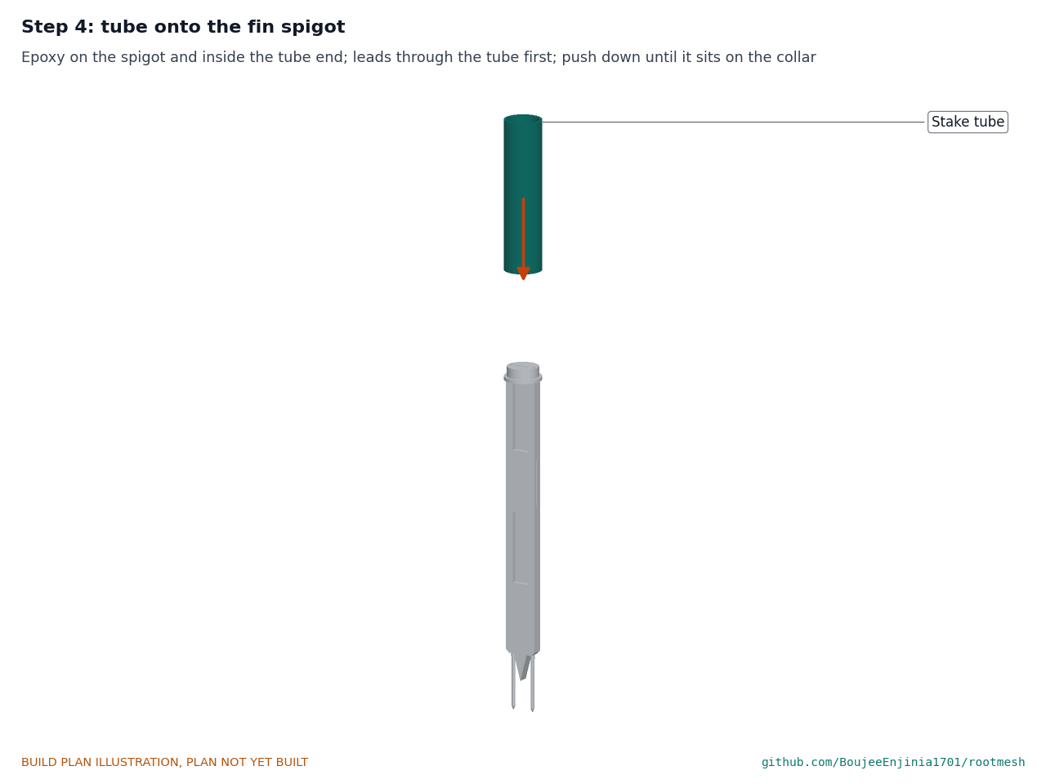
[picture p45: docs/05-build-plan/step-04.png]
Step 4


Thread all the fin leads up through the tube. Coat the spigot and the inside of the tube's bottom end with structural epoxy and push the tube down until it sits on the collar all round. Wipe the joint and stand the fin upright until the epoxy cures.

### Step 5: gland, vent and status LED into the head body

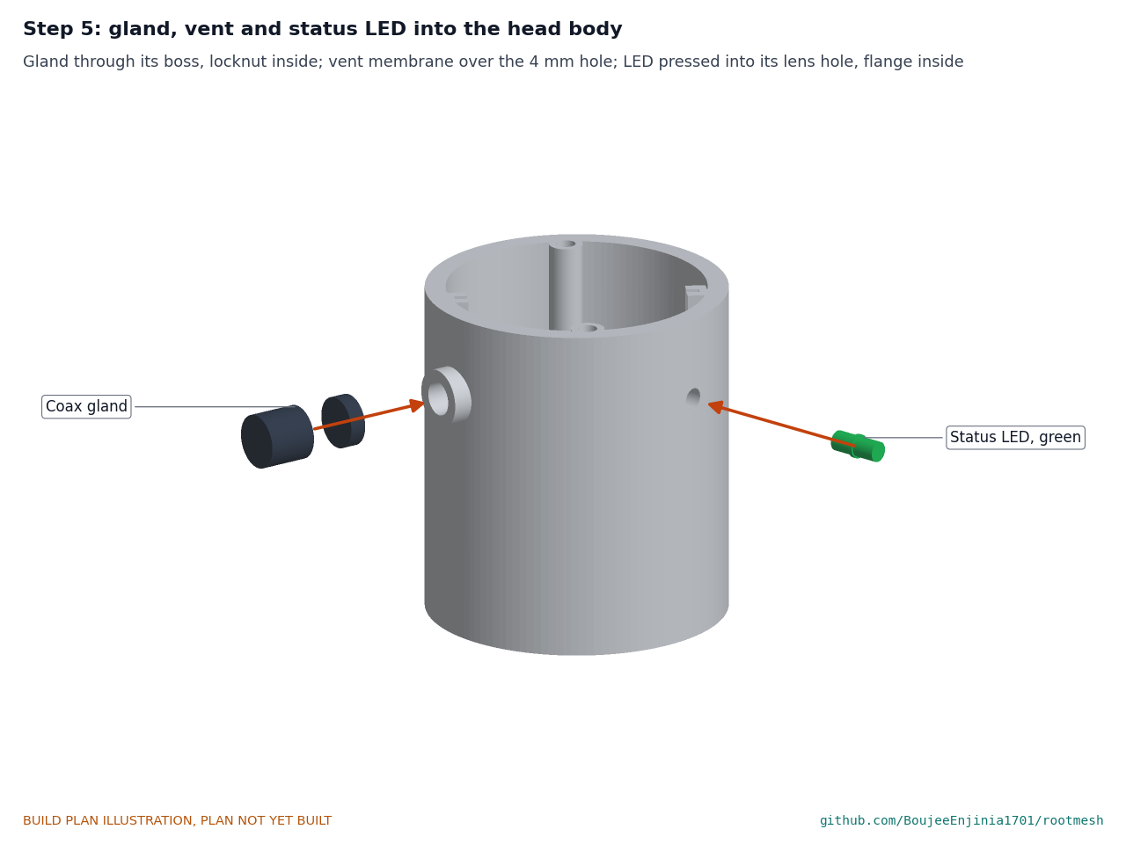
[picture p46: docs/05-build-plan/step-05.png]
Step 5


If not done in section 3.7: inserts flush in the bosses, gland through its boss with the locknut inside, vent membrane on the inside over its hole, and the LED pressed into its lens hole with its flange against the inside wall.

### Step 6: head body onto the tube

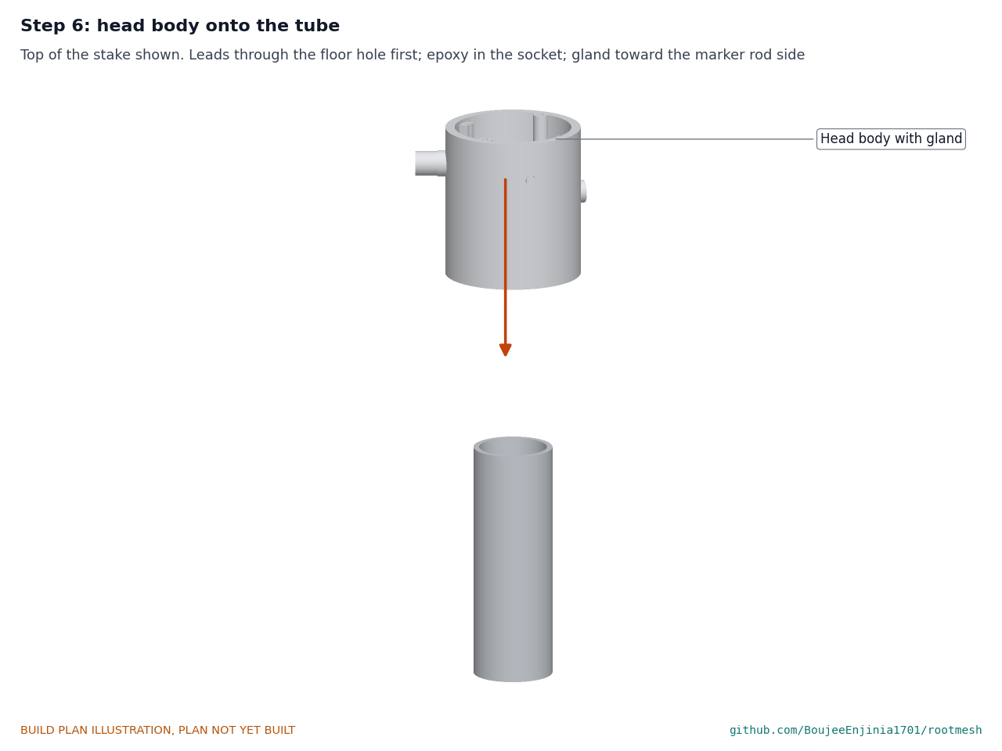
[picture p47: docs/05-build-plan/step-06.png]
Step 6


Thread all the leads up through the floor hole. Coat the inside of the socket and the top of the tube with structural epoxy, and push the body down until 24 mm of tube is inside it, with the gland on the left and turned toward the front (the side the fin's front half faces). Check from above that the fin is square to the board guides. Let it cure.

### Step 7: cell holder and cell down into the tube

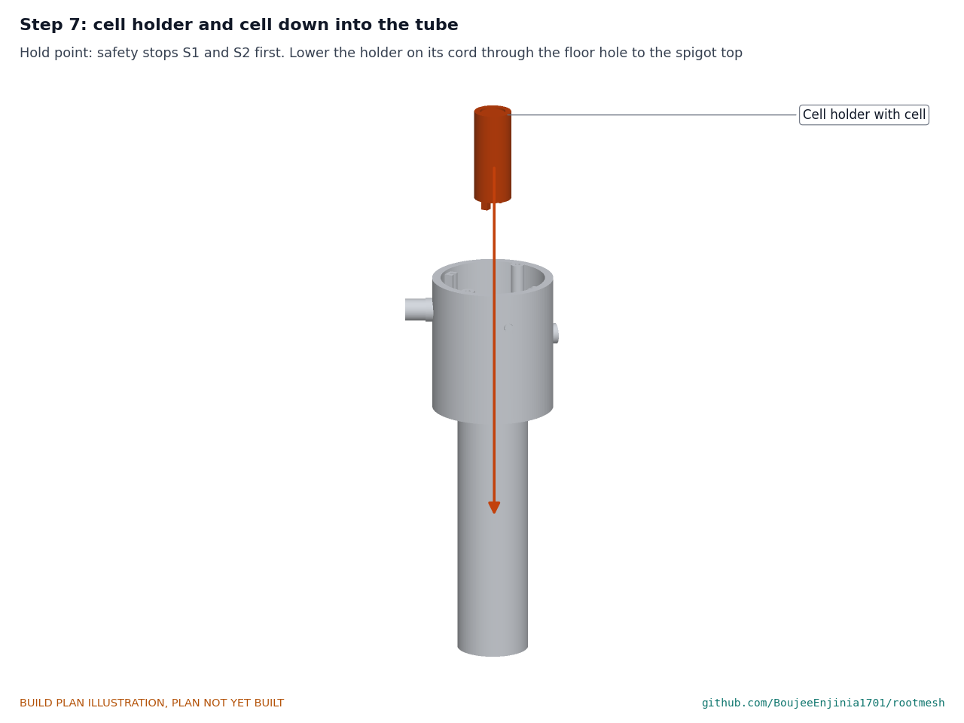
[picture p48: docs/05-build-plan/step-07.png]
Step 7


**Hold point:** safety stops S1 and S2 first. Slide the cell into its holder, pass its leads up, and lower the holder on its cord through the floor hole until its legs stand on the spigot top. Leave the cord's loop and the cell's plug at the top, not yet connected.

### Step 8: controller board into the guides

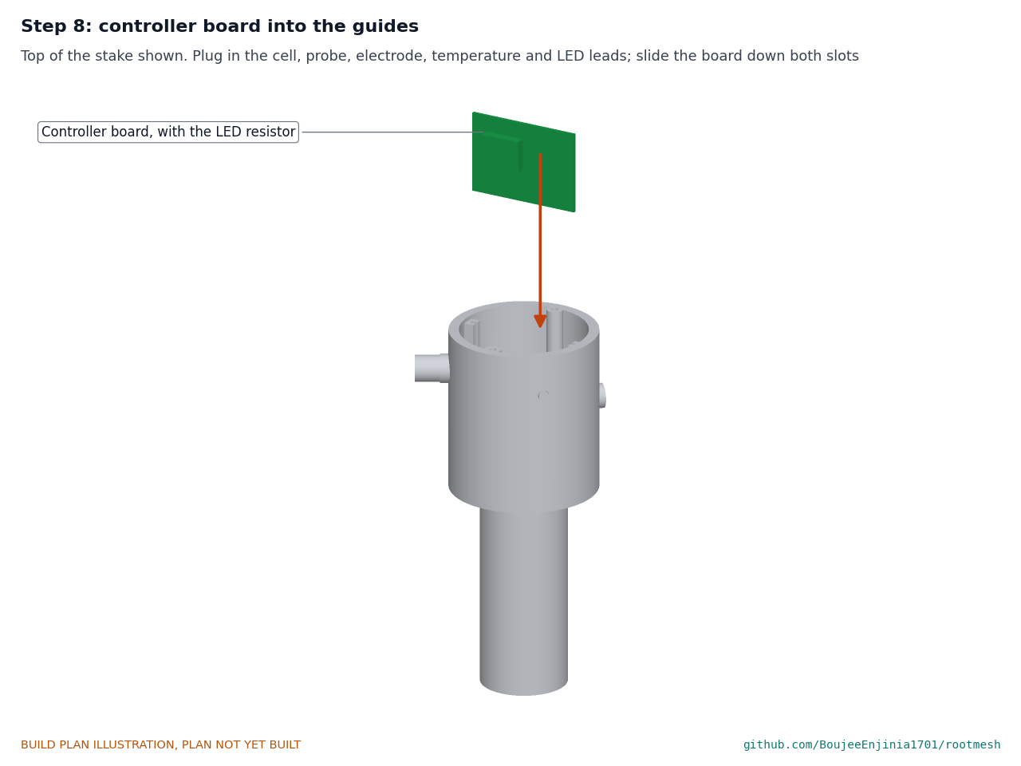
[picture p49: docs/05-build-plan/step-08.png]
Step 8


Plug in the probe, temperature, electrode and LED leads and the antenna pigtail, then slide the board down both guide slots until it stands on their ends. **Hold point:** safety stops S3 and S4 before the cell's plug goes in.

### Step 9: panel into the cap

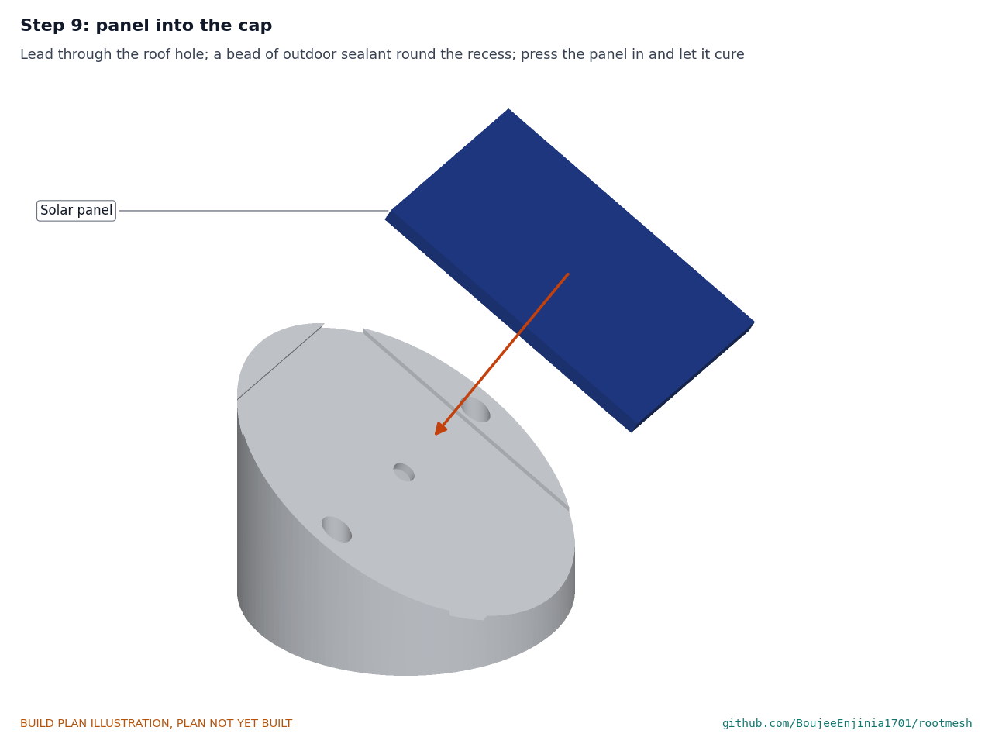
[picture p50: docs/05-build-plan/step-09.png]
Step 9


If not done in section 3.9: lead through the roof hole, sealant round the recess, panel pressed in and cured, O-ring in its groove.

### Step 10: cap onto the body

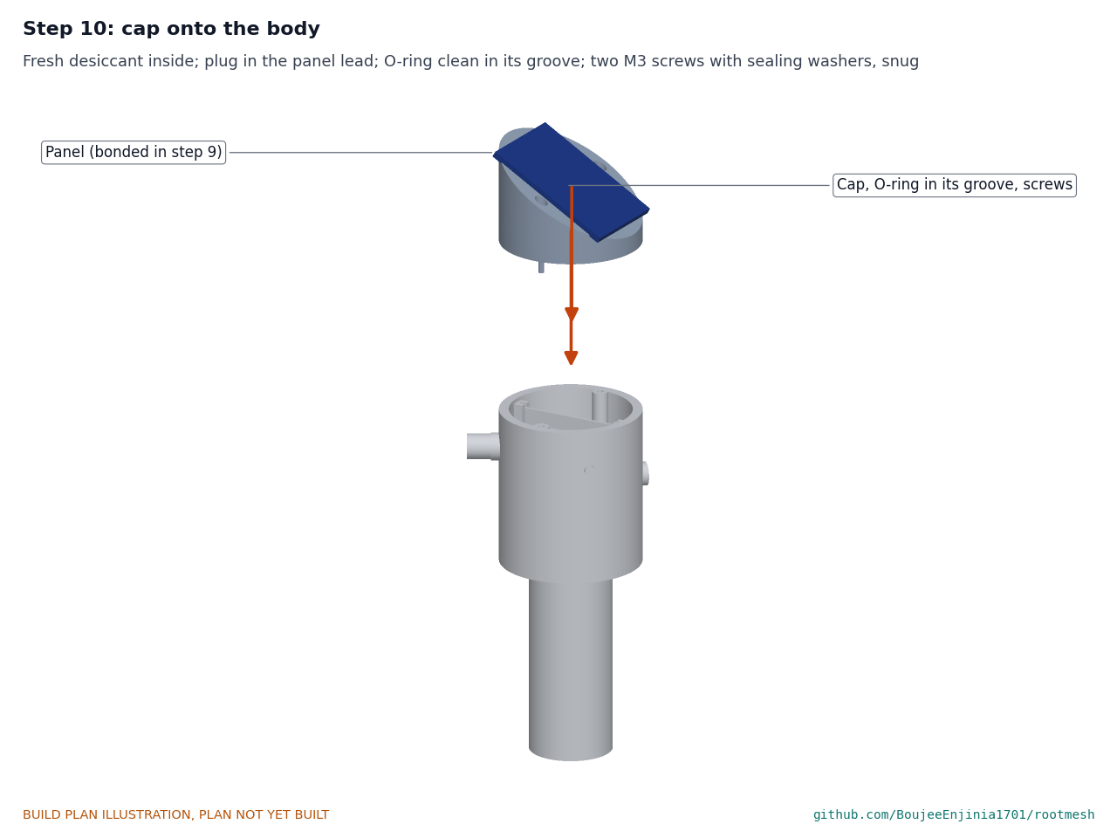
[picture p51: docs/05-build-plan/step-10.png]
Step 10


Put a fresh desiccant sachet in the cavity. Plug in the panel lead. Check the O-ring is clean and seated with no wire across the rim, set the cap on with the panel facing the equator, and fit the two M3 screws with their sealing washers, tightened evenly until snug.

### Step 11: assemble the slot tool

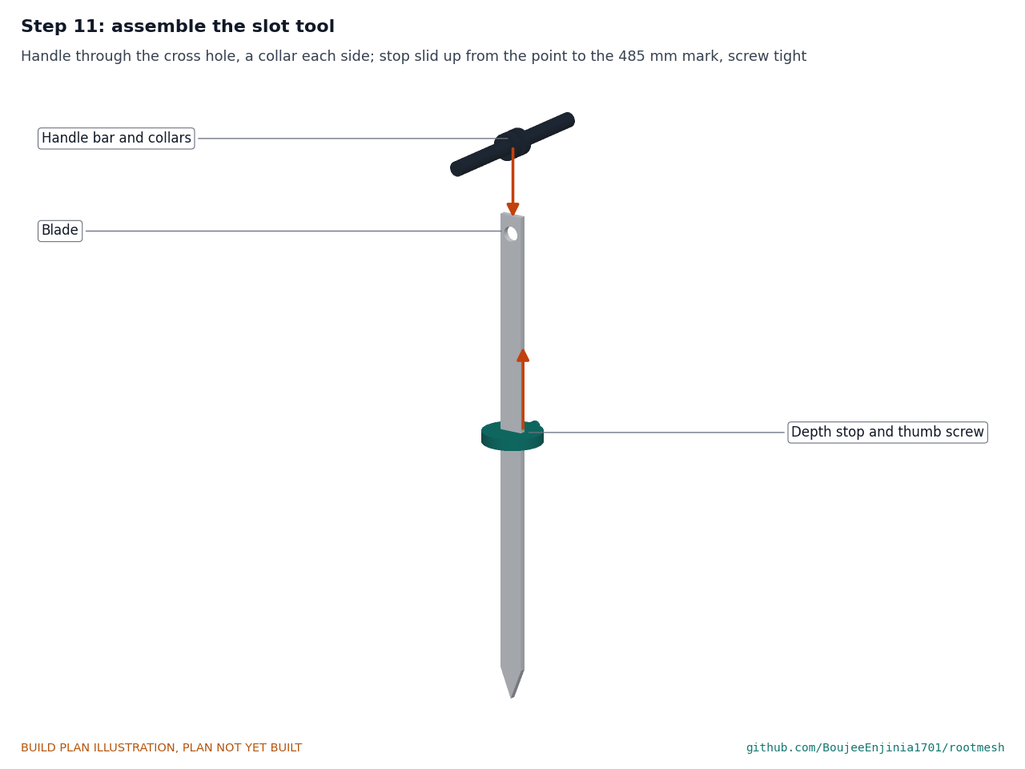
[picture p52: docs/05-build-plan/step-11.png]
Step 11


Handle through the cross hole with a collar each side, set screws tight. Slide the depth stop up from the point to the 485 mm mark, drop in the nut, and tighten the thumb screw.

### Step 12: cut the slot

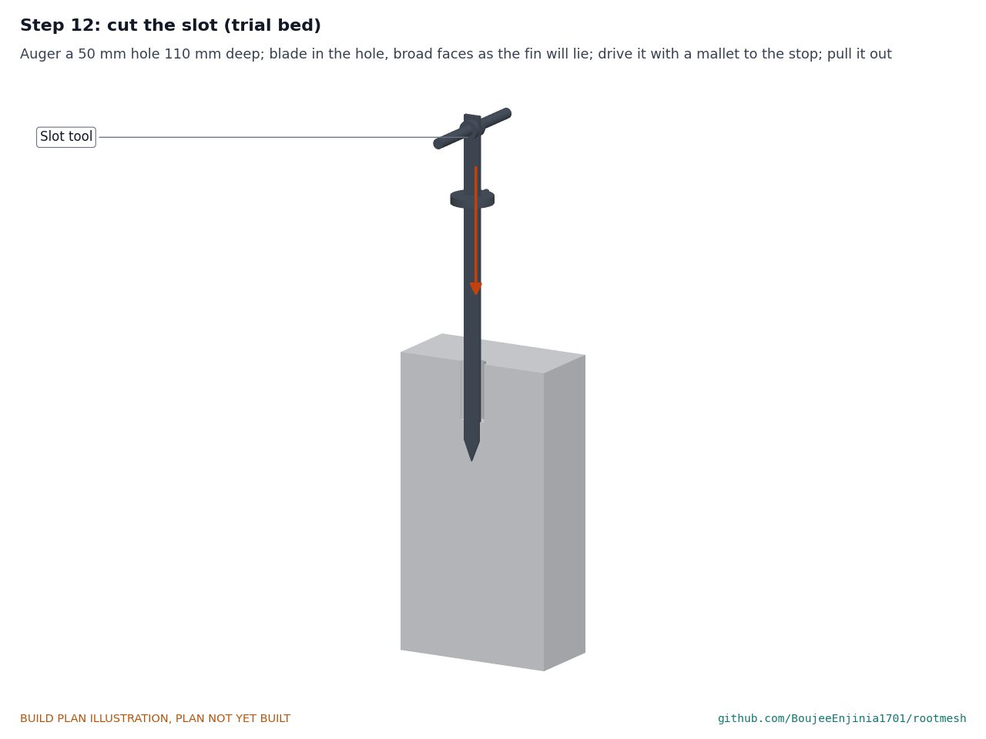
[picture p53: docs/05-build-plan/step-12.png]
Step 12


In the trial bed, auger a 50 mm hole 110 mm deep. Stand the blade in the hole with its broad faces to the front and back, as the fin will lie. Drive it with a mallet on the struck end until the stop sits on the soil, then pull it straight out by the handle. **Hold point:** safety stop S6.

### Step 13: push the stake into the slot

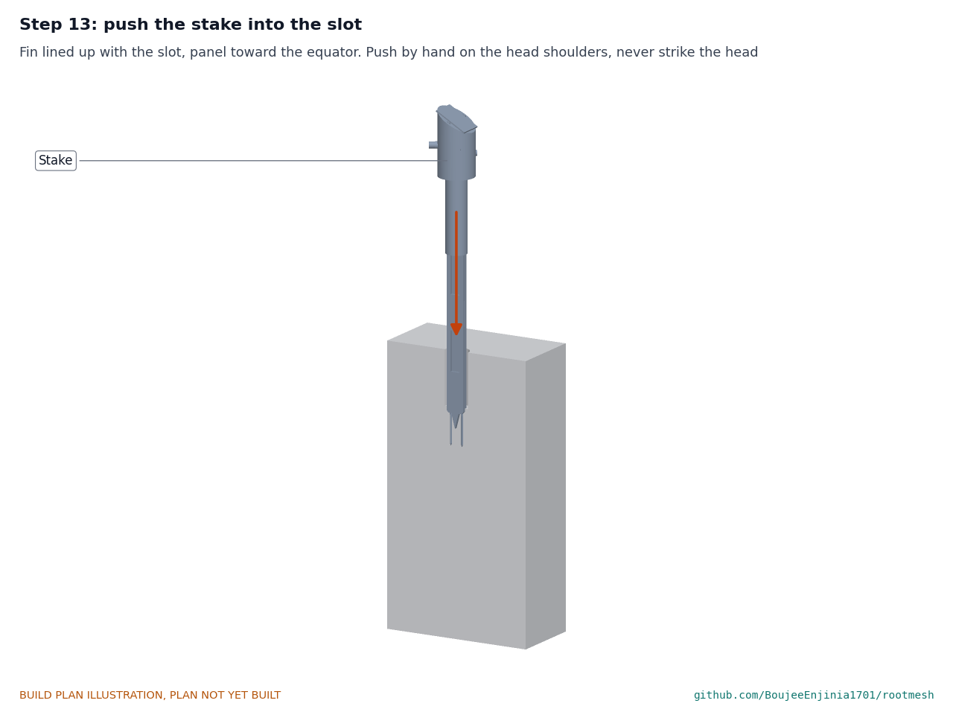
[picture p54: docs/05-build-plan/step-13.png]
Step 13


Line the fin up with the slot, panel toward the equator, and push the stake down by hand on the shoulders of the head until the collar reaches the bottom of the auger hole. Never strike the head. In dry soil, pour a litre of water into the slot first. Firm the soil round the tube.

### Step 14: marker rod beside the stake

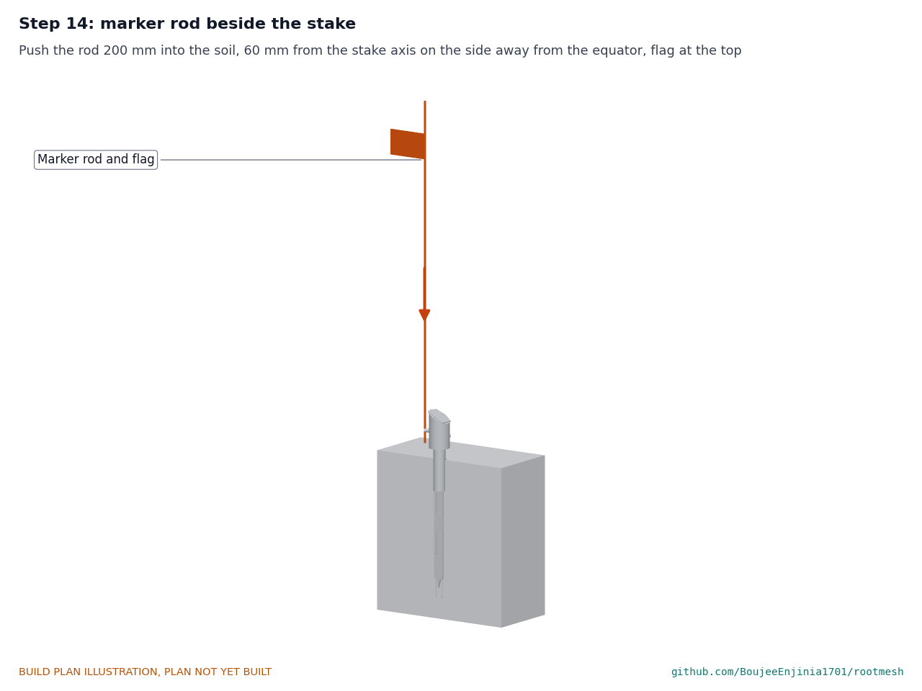
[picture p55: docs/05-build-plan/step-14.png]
Step 14


Push the rod 200 mm into the soil, 60 mm to the left of the stake's centre (on the gland side, away from the equator), flag at the top.

### Step 15: dipole on the top of the rod

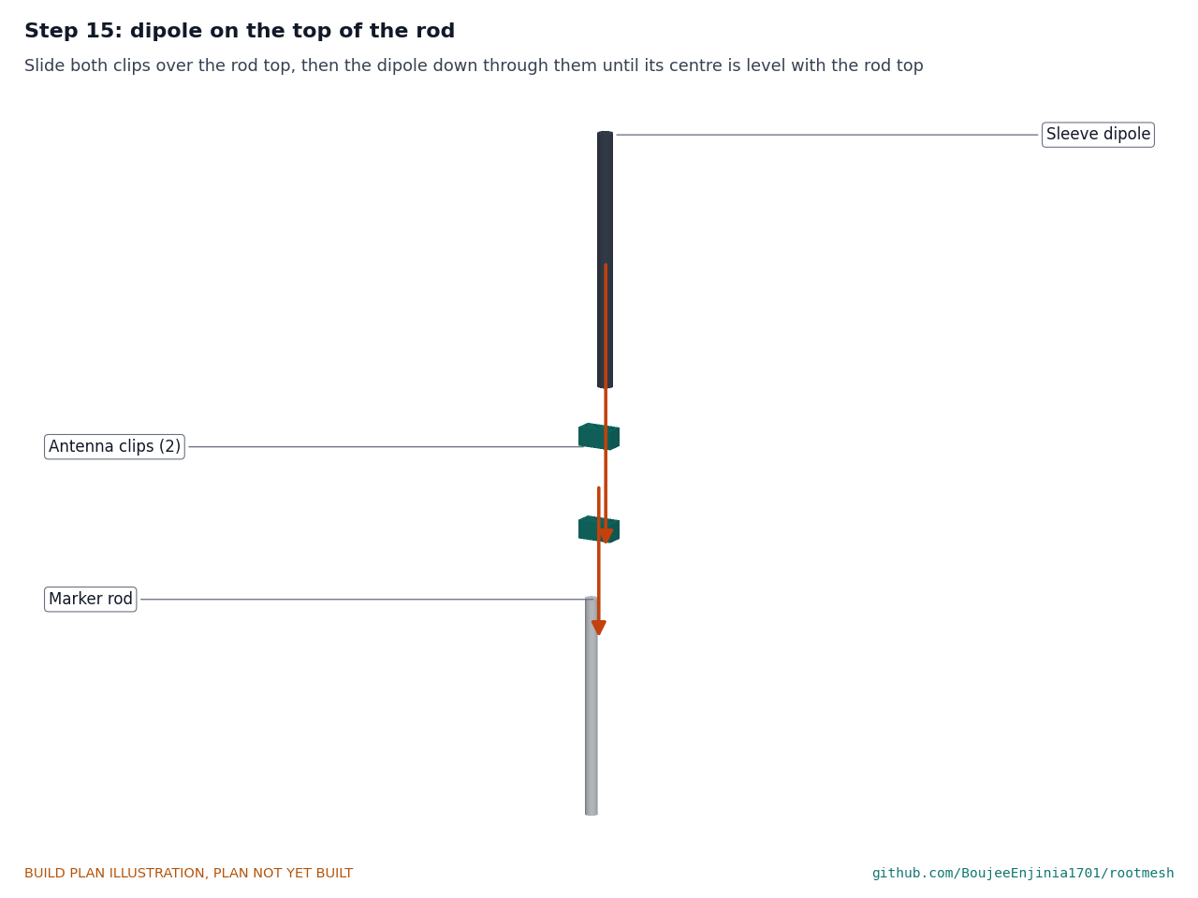
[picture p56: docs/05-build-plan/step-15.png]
Step 15


Slide both clips over the rod top, then the dipole down through them until its centre is level with the rod top; fit a cable tie above and below each clip.

### Step 16: antenna lead into the gland and up the rod

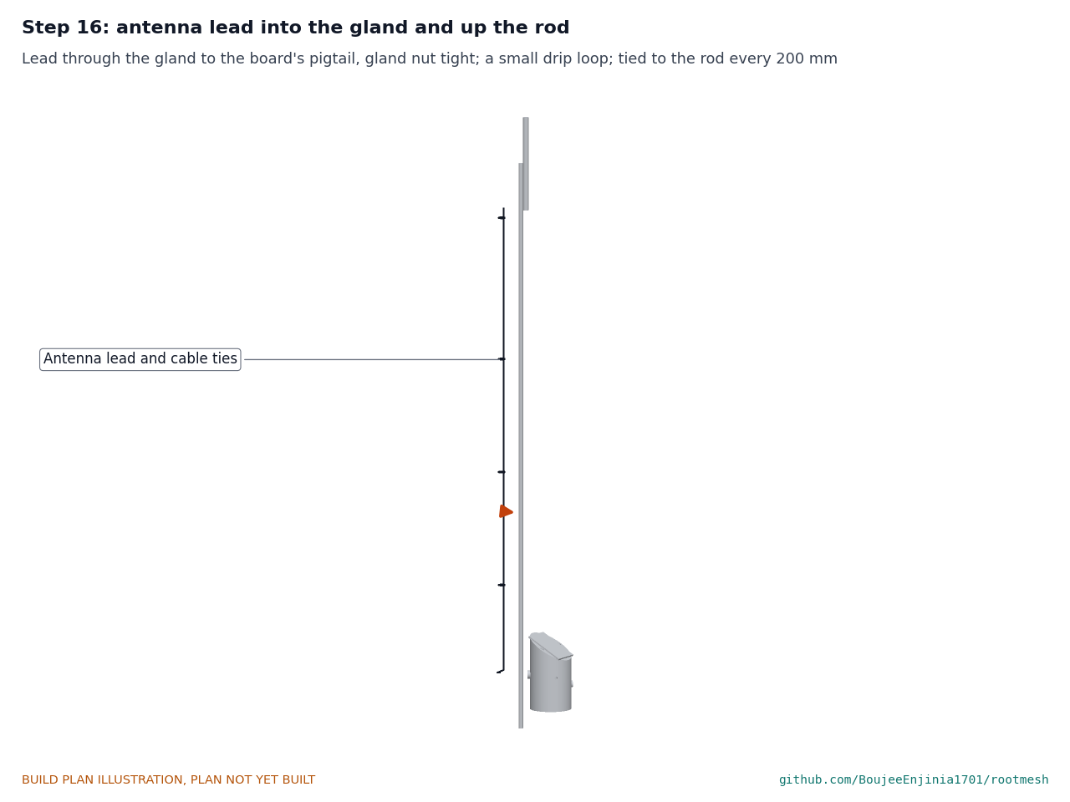
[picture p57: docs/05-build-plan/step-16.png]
Step 16


The lead already runs from the board through the gland: tighten the gland's cap nut on it, leave a small drip loop below the gland, run the lead up the rod to the dipole's connector, and tie it to the rod every 200 mm with cable ties. **Hold point:** safety stop S7 before the radio transmits.

## 5. First checks

These are the checks a TRL 4 test report would record; this plan only lists them. Requirement numbers are those of RMS-REQ-001.

*Table 3. First checks.*

| Check | Requirement | How | Pass when |
| --- | --- | --- | --- |
| Sensing depths | R1, R2, R10 | After step 13, measure from the soil surface to the head's bottom edge; the model puts it 40 mm above the soil | 40 mm, give or take 25 mm, so the windows sit at 150 and 300 mm and the temperature probe at 225 mm |
| Probe outputs | R1 | With the stake out of the ground, read each probe's frequency in air, then with the window wrapped in a wet cloth | Each frequency falls clearly when wet; the two probes read within 10 % of each other in air |
| Temperature | R2 | Stake and a reference thermometer in a bucket of water | Within 0.5 °C |
| Electrode circuit | R3 | Immerse the electrodes in a 1.41 dS/m potassium chloride standard | A steady reading that the calibration can scale; repeat readings within 2 % |
| Charge voltage | R7 | Bench supply at 5 V with a 200 mA limit in place of the panel, cell not plugged in; measure the charger output | 3.60 V, give or take 0.05 V |
| Cold and hot charge stop | R7 | Cell plugged in; replace the cell temperature sensor with a resistor equal to its value at -1 °C, then at 46 °C | No charge current in either case (under 5 mA) |
| Reports | R4, R13 | Join The Things Network and watch the gateway's console for an hour | Three uplinks an hour, decoded on the dashboard |
| Status light | | Watch the head through one uplink, then wake the stake with a magnet | One blink of about 0.1 s after the uplink, three blinks on the wake, dark otherwise |
| Head seal assembled | R8 | Look at the O-ring through the joint and at the panel bead | O-ring evenly squeezed all round; bead unbroken (the spray and immersion tests come later) |
| Push force | R10 | Bathroom scale under the trial bed, or a hand force gauge on the head | Recorded; about 390 N expected in moist loam |
| Installation time | R10 | Time steps 12 to 16 for one stake | 15 minutes or less |
| Heights | R11 | Measure the head top and the dipole centre above the soil | About 171 mm and 1,000 mm |
| Cell change | | Time removing the cap, board and cell holder and putting them back | Recorded for the TRL 4 report |

## 6. Safety stops

Stop at each point. Carry on only when everything listed is true.

- **S1. Before the cell comes into the workshop.** Cell voltage about 2.8 to 3.4 V; no swelling, dents or leaks; a datasheet from its maker; its fuse fitted. A charging spot ready on a non-combustible surface (ceramic tile or steel tray) with a fire extinguisher for electrical fires within reach.
- **S2. Before the cell goes into its holder.** The holder leads' polarity matches the charger's battery terminals, checked with a meter, not by wire colour; the fuse is in the lead.
- **S3. Before any charging source is connected.** The charge voltage is set and measured at 3.6 V with no cell plugged in; the panel lead's polarity is checked at the charger.
- **S4. Before the cell is allowed to charge.** Both charge-stop checks of section 5 pass with the substitute resistors; then the cell's temperature sensor is reconnected.
- **S5. First charge.** Attended the whole time, cap off, stake on the charging spot; cell temperature checked every 15 minutes. Stop if the cell passes 45 °C or 3.65 V. Never bypass the charge stop to gain energy.
- **S6. Before the slot tool is struck.** Eye protection and gloves on; the depth stop tight; feet and hands clear of the blade; nobody else within 2 m. Store the tool with a cover over its point.
- **S7. Before the radio transmits.** The 915 MHz dipole is connected, the radio is set to the US915 band plan and the gateway is the US915 version. Transmitting without an antenna can damage the radio.
- **S8. Before any field installation (outside this plan).** Check with the grower where machinery will pass; keep the flag on the rod; pull stakes before tillage; never install where buried services may run without checking first.

## 7. Tools, skills and workspace

**Tools.** 3D printer with an enclosure, a bed of at least 300 x 300 mm and settings for ASA and PETG; hacksaw with a 24 teeth per inch blade and a mitre box; bench vice; bench drill or a drill in a stand; drills 2 to 10 mm and a step drill or drills up to 20.5 mm; bench grinder or angle grinder with a flap disc; files and a deburring tool; hobby knife; abrasive paper 120 to 400 grit; soldering iron with a heat-set insert tip; flux for stainless steel; heat gun; wire strippers and crimper; multimeter; bench power supply with an adjustable current limit (0 to 15 V, 0 to 2 A); M3 hex key; spanners for the gland; a 50 mm hand auger; a 1 kg rubber or dead-blow mallet; clamps and two straight battens about 400 mm long; tape measure, steel rule and calipers; stopwatch.

**Skills.** No certified trade is needed. 3D printing with engineering plastics, two-part epoxy work, basic metalwork (sawing, drilling, grinding), through-hole soldering, and care with lithium cells and a bench power supply. All circuits are extra-low voltage: 3.6 V at most from the cell and about 6 V from the panel. The bench supply must be a certified, undamaged unit; no mains wiring is part of this build (the gateway uses its own certified USB supply).

**Workspace.** A bench about 1.2 x 0.6 m; a metalwork corner apart from the electronics so steel dust stays off the modules; a ventilated place for printing and epoxy; the charging spot of S1; a trial bed of loam at least 600 mm deep and 300 mm across, outdoors or in a large tub.

**Personal protective equipment.** Safety glasses for cutting, drilling, grinding, soldering and striking; nitrile gloves for epoxy; work gloves for bar stock and the slot tool; hearing protection when grinding; no gloves near a turning drill.

## 8. Where the numbers come from

- Model and constructability checks: `cad/src/model.py` (`python cad/src/model.py --check`); STEP and STL exports in `cad/step/` and `cad/stl/`.
- Pictures: `cad/src/build_plan_media.py`, using `.kit/build_views.py`; written to `docs/05-build-plan/` and `cad/drawings/RMS-DWG-101` to `RMS-DWG-110`.
- General arrangement: `cad/drawings/RMS-DWG-001.pdf`, Rev P5.
- Calculations: `docs/04-calcs/01-sizing.md` (RMS-CAL-001 v0.5) and `docs/04-calcs/sizing.py`; push force [G1], [G4]; cell depth [F2], [F4]; head air [F3]; cost [H1].
- Bill of materials: `bom/bom.csv`.
- Decisions: `docs/decisions/0003-design-for-construction.md` (RMS-DDR-003), with RMS-DDR-001 and RMS-DDR-002.
- Requirements: `docs/03-requirements.md` (RMS-REQ-001 v0.7).

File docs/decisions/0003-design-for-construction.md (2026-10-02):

---
doc_id: RMS-DDR-003
title: RootMesh design for construction
project: RootMesh
doc_type: Design decision record
version: "0.2"
status: Draft
date: '2026-10-02'
author: Amish Chadha
license: CERN-OHL-S-2.0
revisions:
- version: "0.1"
  date: '2026-10-01'
  author: Amish Chadha
  change: Changes that make the concept physically buildable, with the reason for each; made under Amish's 2026-09-30 instruction to make the design physically buildable; open for his review
- version: "0.2"
  date: '2026-10-02'
  author: Amish Chadha
  change: Accepted by Amish on 2026-10-02, including the recommendations for A1 and A2
---

# 0003: Design for construction

- **Date:** 2026-10-01
- **Status:** accepted. Amish, 2026-10-02: "i approve your recommendations for all 555 open decisions." This covers every change in Tables 1 and 2 and the recommendations in Table 3 (A1 and A2), which are now decided as recommended and recorded in the design decisions register (RMS-DEC-001).

## Context

On 2026-09-30 Amish approved the build plan format and asked for it across all repos, and wrote: "If you are realising that the design cannot be built as per concept - fix the design assumptions to match and be physically feasible as you draw the illustrations." The TRL 3 model of RootMesh (RMS-DDR-001 and RMS-DDR-002) showed what the stake does, but it was a massing model: several of its parts could not be made, fitted or fixed as drawn. Checking it with build123d (overlaps, contacts, assembly order and the process for each part) found the eleven problems in Table 1.

The changes keep what the stake does: the same sensing depths (150 mm and 300 mm), electrode spacing and bare length, temperature probe depth, cell depth, panel size and tilt, head height above grade, antenna height on the marker rod, reporting, radio and power design. Nothing here changes the pitch or the safety case. Every change is in `cad/src/model.py`, which now runs 331 constructability checks (`python cad/src/model.py --check`): no two parts overlap, every joint touches (glued joints and slip fits within 0.6 mm), the board and cell holder pass the openings they must pass, the cap screws clear the panel, the gland nut clears the board, and each fin half fits a 300 x 300 mm print bed laid diagonally. All 331 pass.

## Decision

*Table 1. Changes made to the model, the BOM and the calculations.*

| # | Problem in the concept | Change made | Why this way |
| --- | --- | --- | --- |
| P1 | The head was one printed piece whose only opening was a 28 mm hole above the socket, so the 56 mm controller board could not be put in. The O-ring sat inside solid head material above the tube end and sealed nothing, nothing held the head on the tube, and the cavity broke through the sloped top beside the panel. | The head is a printed body and a removable cap parted 120 mm above grade. The body (5 mm wall, was 3 mm) has a 26 mm socket bonded over the tube, a 3 mm floor with a 28 mm hole, and two bosses with M3 heat-set inserts. The cap has a 3 mm roof under the panel, a 1 mm panel recess, a lead hole, a 64 x 2 mm O-ring in a groove in its rim face (a face seal on the body rim), and two M3 screws with sealing washers in counterbores clear of the panel. | The board must go in from the top, so the head must open there. A face seal on the rim keeps the inside of the body clear for the board; the 5 mm wall gives the O-ring a land. This follows option B of the 2026-09-26 appearance review (a separate cap carrying the panel), with a face seal instead of a second radial O-ring. |
| P2 | The controller board floated in the cavity with no fixing. | Two printed guide ribs on the body walls with 1.8 mm slots; the board slides down them and stands on the slot ends, 76 to 116 mm above grade. | Printed with the body, no extra part; the board lifts out after the cap. |
| P3 | The fin's top ran 10 mm inside the tube and its corners cut into the tube wall (a 36 mm wide fin in a 36 mm bore). The upper probe window reached 110 mm deep, 10 mm above the tube's bottom end, so it was inside the tube. The tube end had nothing to sit on and no seal. | A 42 mm collar, 4 mm thick, tops the fin at 110 mm below grade, with a 35.4 mm spigot, 11 mm long, bonded inside the tube. The tube (still 170 mm) moves up 14 mm to run from 106 mm below grade to 64 mm above it; the head socket is deepened so the head stays at the same height. The upper window keeps its centre at 150 mm and ends at the collar. | Keeps both sensing depths exactly (RMS-DDR-001, D6) and gives the tube a positive stop and a glued, sealed joint. The auger hole becomes 110 mm deep (was 120 mm). |
| P4 | The fin was a solid print: the probes floated in through-windows with nothing to hold them and no route for their wires, and nothing held the temperature probe or the electrodes. | The fin is printed in two halves split on its mid-plane and glued with epoxy. Inside: 0.9 mm slots for the probe board edges, 3.4 mm pockets for the probe electronics (front half), two 3.5 x 5 mm wire channels in the side rails from the foot to the spigot top, a cross channel for the lower probe, a 6.2 mm bore for the temperature probe and 4.1 mm grooves for the electrodes. The windows narrow from 28 to 19 mm so each board edge is held 2 mm on each side and the rails have room for the channels. | A two-part print is the simplest way to make closed internal channels and to trap the sensors, and the epoxy glue line also pots them. |
| P5 | The temperature probe stood 7 mm proud of the fin edge, outside the 32 mm slot that the slot tool cuts, so it would be torn off when the fin is pushed in. | The sheath lies in the bore in the fin edge, 0.4 mm proud. | It still touches undisturbed soil at 225 mm and survives installation. |
| P6 | The fin tip was a round cone 24 mm across, twice the fin thickness, overlapping the electrodes; each electrode was modelled as three separate pieces with a gap. | A wedge tip 16 mm wide and 30 mm long between the electrodes, with flat shoulders where the electrodes leave the foot. Each electrode is one 80 mm rod: 15 mm held in the foot grooves, 5 mm in a heat-shrink sleeve, 60 mm bare. | The bare length and spacing set the EC cell constant and are unchanged, so section D of RMS-CAL-001 stands. |
| P7 | The cell floated in the tube. | A printed holder, 22 mm across, stands on two legs on the spigot top, with the cell centre still 62 mm below grade. It lifts out on a cord through the 28 mm floor hole once the cap and board are out. | Holds the cell at the depth the thermal calculation uses and gives a way to change it without cutting the stake. |
| P8 | The coax gland boss sat 120 mm above grade, now the cap's parting line, and in line with the board. | The gland moves to 100 mm above grade, turned 30 degrees toward the front, on a boss with flat faces outside and inside for the gland and its locknut. | The locknut clears the board and module by about 2 mm (checked). |
| P9 | The vent boss at the back would cut into a cap screw boss. | The vent moves to the back right, 82 mm above grade. | Same vent, clear of the bosses and guides. |
| P10 | The antenna clip was a block overlapping the rod; the dipole was held at one point; the lead ran 1.5 mm off the rod in the air. | Two printed clips, each with an 8.2 mm rod hole and a 10.2 mm dipole hole, centred 925 and 985 mm above grade; the lead runs along the rod held by four cable ties. | A real fixing that slides on by hand; the dipole stays centred 1,000 mm above grade (RMS-DDR-001, D2). |
| P11 | The slot tool's 20 mm handle lay in the plane of the 32 mm blade, passing through it, and the depth stop was loose. | The handle passes through a 20.5 mm cross hole 25 mm below the struck end, held centred by two 20 mm shaft collars. The printed stop is clamped to the blade by an M5 thumb screw in a trapped nut. The blade is 650 mm long overall, as the BOM says (the model had 635 mm). | No welding; the stop can be set to the electrode tip depth (485 mm) and moved for other stakes. |

*Table 2. Knock-on changes.*

| Item | Change | Reason |
| --- | --- | --- |
| BOM | Line 2 head body and cap ($3.50, was $3.00); line 7 fin in two halves ($3.00, was $2.50); lines 4, 5, 11 and 12 re-described; line 15 slot tool fixings ($14.00, was $10.00); new line 16, head fixings and bonding ($2.50 per stake). One stake $55.50 to $59.00; pilot set $266.50 to $281.00. | Parts added for construction. |
| Cost | Value-engineering target: USD 300 (`budget_usd`, unchanged). Estimated cost of the constructable design: USD 281 (USD 19 under the target). R12's $60 per stake is met by $1.00 [H1]. | |
| Installation (R10) | Auger hole 110 mm deep; fin pushed 310 mm into undisturbed soil instead of 300 mm. With the slot tool 386 N in moist loam (was 376 N) and 1,245 N in firm dry loam (was 1,216 N) [G4]. Status unchanged: at risk. | P3 lowered the start of undisturbed soil by 10 mm. |
| Cell temperature (R9) | Deepest cell centre that fits is now 62 mm (46.8 °C), where the cell already sits; v0.2 found 65 mm (46.5 °C) [F4]. Status unchanged: at risk. | The holder base takes the 3 mm the cell could have dropped. |
| Sealing (R8) | Head air 272 cm³ (was 308 cm³); pressure rise unchanged at 15.1 kPa [F3]. A second seal (the cap's O-ring) is added. Status unchanged: not verifiable at TRL 3. | Thicker body wall. |
| Documents | RMS-CAL-001 v0.3, RMS-REQ-001 v0.5, RMS-PRC-001 v0.5; RMS-DWG-001 Rev P4; making sketches RMS-DWG-101 to 110; build plan RMS-BLD-001 and register RMS-DEC-001 added. No requirement changed status. | Follows the model. |

*Table 3. Proposed, then accepted by Amish as recommended on 2026-10-02.*

| # | Question | Options | Recommendation |
| --- | --- | --- | --- |
| A1 | Each fin half is 355 mm long with its collar and spigot. It fits a 300 x 300 mm print bed laid diagonally, but not the common 220 or 256 mm beds. | (a) print on a 300 mm class printer or through a print service; (b) split each half into two lengths with a glued lap joint between the windows. | (a): a joint between the windows would add a seam across the wire channels and the temperature probe. Accepted 2026-10-02. |
| A2 | The tube is now bonded into the head body and onto the fin, so the stake is one permanent piece below the cap. The cell and board are reached through the cap; the fin cannot be separated from the head for repair. | (a) bonded, as modelled; (b) a second O-ring and two screws at the head socket, so the head comes off the tube. | (a) for the prototype: fewer seals in the ground, and the cell is still reachable. Revisit after a soak test at TRL 4. Accepted 2026-10-02. |

## Consequences

- `design_state: constructable` in `project.yaml`. The build plan RMS-BLD-001 shows every component and step in pictures generated from the model (`cad/src/build_plan_media.py`).
- Requirement status is unchanged: 8 met, 5 at risk (R1, R5, R9, R10, R14), 1 not verifiable at TRL 3 (R8), none not met (RMS-CAL-001 v0.3).
- The open item from the 2026-09-26 appearance review on a separate solar cap is answered by P1 in this record, accepted with the rest of it by Amish on 2026-10-02.
- The photoreal renders (`media/render-*.png`), `media/card.png`, `media/social-preview.png` and the appearance model `cad/src/product_model.py` still show the concept head, fin and antenna clip; they need updating on Amish's Mac, where Blender is.
- The probe boards, temperature probe, cell, O-ring, gland, inserts and PVC pipe are chosen at TRL 4; the sizes in the register's "to confirm" list must be checked against the parts bought, and the slots, pockets, bores and holes moved to suit.

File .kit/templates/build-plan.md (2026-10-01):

---
doc_id: PRJ-BLD-001
title: Project prototype build plan
project: Project name
doc_type: Build plan
version: "0.1"
status: Draft
date: YYYY-MM-DD
author: Amish Chadha
license: CERN-OHL-S-2.0
revisions:
  - version: "0.1"
    date: YYYY-MM-DD
    author: Amish Chadha
    change: First build plan; design made constructable
---

# Project prototype build plan

**Plan, not yet built.** How to build the first proof-of-concept prototype, component by component. Building and testing to it is TRL 4 work. Decisions still to be made are kept in the design decisions register (`docs/06-design-decisions.md`), not here.

## 1. What you are building

Every component, pulled apart and numbered in build order

One short paragraph: what the prototype is, how many components, which are made and which are bought, and the main ways they are made.

## 2. What changed to make it buildable

| Component | The concept had | The buildable design has | Why |
| --- | --- | --- | --- |

## 3. Making the components

### 3.1 Component name

Making sketch

**What it is and what it is made from.**

**How to make it.**

1. Mark out ...
2. Cut ...

**How it fits the parts next to it.**

Close-up of the joint

**Check before moving on.**

## 4. Putting it together

### Step 1: ...

Step 1

## 5. First checks

| Check | Requirement | How | Pass when |
| --- | --- | --- | --- |

## 6. Safety stops

## 7. Tools, skills and workspace

## 8. Where the numbers come from

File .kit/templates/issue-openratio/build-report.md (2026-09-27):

---
name: Build report
about: Tell us what happened when you built, printed or tested part of this design
title: "Build report: "
labels: build-report
---

This is a research and educational prototype, not a medical device. It is a TRL 3 concept and is not released for fabrication. If you build any part of it, you do so at your own risk. Reports help everyone.

**What you built** (part, sub-assembly or test)

**Materials, tools and settings**

**What worked**

**What did not work, with photos or measurements if you have them**

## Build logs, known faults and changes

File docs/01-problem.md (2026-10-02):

---
doc_id: RMS-PRB-001
title: RootMesh problem statement
project: RootMesh
doc_type: Problem statement
version: "0.4"
status: Draft
date: '2026-10-02'
author: Amish Chadha
license: CERN-OHL-S-2.0
revisions:
- version: "0.1"
  date: '2026-09-24'
  author: Amish Chadha
  change: Initial scaffold
- version: "0.2"
  date: '2026-09-25'
  author: Amish Chadha
  change: Populate to TRL 2 (problem, users, context, constraints, out of scope, prior work with sources)
- version: "0.3"
  date: '2026-09-25'
  author: Amish Chadha
  change: Record Amish's decisions (RMS-DDR-001) on the budget reading, power and network; update open questions
- version: "0.4"
  date: '2026-10-02'
  author: Amish Chadha
  change: First users and region (US915; Texas A&M AgriLife Extension as first candidate), as decided by Amish on 2026-10-02
---

# RootMesh problem statement

Most small growers decide when and how much to irrigate by feel, by the look of the crop or by the calendar, because field-ready soil sensors that report wirelessly cost $150 to $600 or more per measurement point. A sensor stake that measures root-zone moisture, temperature and salinity for about $56 in parts, runs on a small solar panel and reports over LoRaWAN to one gateway at the farmhouse would put measured soil data within reach of farms that cannot justify commercial systems.

## The problem

Agriculture uses about 70 % of global freshwater withdrawals ([Our World in Data, "Water Use and Stress"](https://ourworldindata.org/water-use-stress)), so how well irrigation is scheduled matters for water, energy and yield. Scheduling with soil water sensors works: a systematic review of U.S. studies found that sensor-based scheduling used about 38 % less water than traditional scheduling and about 20 % less than evapotranspiration replacement, with similar or larger yields ([Datta and Taghvaeian 2023, *Agricultural Water Management* 278](https://www.sciencedirect.com/science/article/pii/S0378377423000136)). Yet in most U.S. states fewer than 25 % of irrigated farms report using soil moisture sensors to decide when to irrigate ([Ogallala Water CAP, citing the USDA NASS Irrigation and Water Management Survey](https://ogallalawater.org/soil-moisture-monitoring/)). Adoption is lower still on small farms and outside high-income countries.

Three gaps keep sensors out of the field:

1. **Cost per point.** A research-grade moisture, temperature and EC sensor such as the METER TEROS 12 sells for about $620 without a logger ([TEquipment listing](https://www.tequipment.net/HOBO-by-Onset/TEROS-12-US/Moisture-Meters/)). Even a low-cost commercial LoRaWAN node such as the Dragino SE01-LB or SE01-LS costs about $150 to $170 ([Choovio listing](https://www.choovio.com/product/se01-lb-lorawan-soil-moisture-ec-sensor/)). A field needs several points to capture variation in soil and slope, so the total quickly exceeds what a small grower will spend.
2. **Field hardiness of cheap parts.** The hobby capacitive moisture boards that cost a few dollars are not built for burial: the stock NE555 timer is unreliable at 3.3 V, the onboard regulator drops out below about 3.4 V, the cut board edges absorb water and corrode within weeks, and the output drifts with temperature ([Cave Pearl Project 2020](https://thecavepearlproject.org/2020/10/27/hacking-a-capacitive-soil-moisture-sensor-for-frequency-output/)). Garden-grade sensors therefore fail before a season ends.
3. **Calibration and interpretation.** Factory calibrations for capacitance sensors carry about three times the error of a site-specific calibration, and growers rarely have the means to calibrate ([Datta and Taghvaeian 2023](https://www.sciencedirect.com/science/article/pii/S0378377423000136)). Raw numbers without a threshold also do not tell a grower whether to irrigate today.

RootMesh aims to close all three: a stake built from low-cost parts but designed for burial, with a simple field calibration routine and a dashboard that shows root-zone depletion against a threshold the grower sets.

## Users and context

| User | Need | Context |
| --- | --- | --- |
| Small grower (vegetables, fruit, field crops, about 0.5 to 10 ha) | Know when the root zone is drying and how deep water has reached, without walking every bed | Drip, furrow or sprinkler irrigation; phone in hand; limited budget |
| Orchard or vineyard manager | Track deep moisture and salinity through the season in a few representative blocks | Perennial crops, stakes stay in place for months |
| Market or community garden coordinator | Share one gateway across many plots and volunteers | Mixed crops, public site, risk of tampering |
| Extension agent or researcher | Deploy many cheap points to map variation and teach irrigation scheduling | Short trials, needs raw data export |
| Farm technician | Install, calibrate, move and repair stakes with hand tools | Hand auger, multimeter, basic soldering |

### Operating environment

- **Soil:** sand to clay loam, with stones; volumetric water content from about 5 % (dry sand) to 50 % (saturated clay); bulk soil EC up to a few dS/m in saline or heavily fertigated fields.
- **Depth of interest:** the main root zone of most vegetable and field crops, about 100 to 400 mm.
- **Climate:** air from -10 to 45 °C; a dark enclosure in full sun can reach 60 to 70 °C (estimate); rain, irrigation spray, flooding of furrows; freezing topsoil in winter in temperate regions.
- **Radio path:** one gateway at the farmhouse or a shed, typically 100 m to 1 km from the stakes, with crops, trees and buildings in the path; stakes sit close to the ground.
- **Operations:** tillage, cultivation, mowing and harvest machinery pass the stakes; livestock and people may disturb them.
- **Power:** no mains in the field; sun on the stake head may be shaded by the crop canopy late in the season.

## Constraints

- Garage-buildable prototype. The project budget is $300 USD for a pilot set of three stakes and one gateway (decided by Amish, 2026-09-25; RMS-DDR-001, D4).
- Parts available from general electronics retailers; enclosure parts printable or from a hardware store.
- No mains power in the field; solar harvest with a small rechargeable LiFePO4 cell (RMS-DDR-001, D1 and D5).
- Operate within license-free radio rules for the region (for example ETSI EN 300 220 duty cycles in Europe, FCC Part 15 in the United States) and within The Things Network fair use policy if the free community network server is used ([The Things Network, "Duty Cycle"](https://www.thethingsnetwork.org/docs/lorawan/duty-cycle/)).
- The grower owns the data. The system must work without a paid cloud subscription. The pilot uses The Things Network's free community server (RMS-DDR-001, D3).
- Removable by hand before tillage or harvest, and reinstallable at the same depth.

## Out of scope

- Automatic valve or pump control. RootMesh informs the irrigation decision; it does not actuate irrigation at this stage.
- Nutrient (N, P, K) or pH sensing.
- Satellite or drone moisture products.
- Crop models or yield prediction beyond a simple root-zone depletion view.
- A new radio protocol or a new gateway design.

## Prior work

- **Commercial LoRaWAN soil nodes.** Dragino LSE01 and SE01 measure moisture, temperature and EC with an FDR probe in an IP66 enclosure, on a primary Li-SOCl2 cell or a solar panel with a Li-ion cell ([Dragino LSE01](https://www.dragino.com/products/lora-lorawan-end-node/item/159-lse01.html); [Choovio SE01 listing](https://www.choovio.com/product/se01-lb-lorawan-soil-moisture-ec-sensor/)). They prove the architecture and set the price reference, but measure at one depth and are closed designs.
- **Research-grade sensors.** METER TEROS 12 and similar sensors set the accuracy reference for moisture, EC and temperature at about $620 per sensor ([TEquipment listing](https://www.tequipment.net/HOBO-by-Onset/TEROS-12-US/Moisture-Meters/)).
- **Hacked hobby capacitive sensors.** The Cave Pearl Project documents how to make the v1.2 capacitive board usable in the field: swap the NE555 for a TLC555, bypass the regulator, read frequency and seal the edges in epoxy ([Cave Pearl Project 2020](https://thecavepearlproject.org/2020/10/27/hacking-a-capacitive-soil-moisture-sensor-for-frequency-output/)). RootMesh adopts these fixes.
- **Capacitance sensor behavior.** Low-cost capacitance sensors respond to soil EC and temperature as well as water, more strongly at low measurement frequency ([Kizito et al. 2008, *Journal of Hydrology*](https://www.sciencedirect.com/science/article/abs/pii/S0022169408000462)). This is a reason to measure EC and temperature at the same point.
- **Irrigation scheduling methods.** FAO Irrigation and Drainage Paper 56 defines root-zone depletion and management allowed depletion, the basis for a simple "irrigate now" threshold ([Allen et al. 1998, FAO-56](https://www.fao.org/4/x0490e/x0490e00.htm)). FAO Paper 29 gives crop salinity tolerance thresholds in terms of soil EC ([Ayers and Westcot 1985, FAO-29](https://www.fao.org/4/t0234e/t0234e00.htm)).
- **Community LoRaWAN.** The Things Network offers a free community network server with a fair use limit of 30 s of uplink airtime per node per day ([The Things Network, "Duty Cycle"](https://www.thethingsnetwork.org/docs/lorawan/duty-cycle/)), and low-cost indoor gateways such as The Things Indoor Gateway sell for about $79 ([Seeed Studio listing](https://www.seeedstudio.com/The-Things-Indoor-Gateway-EU-p-4709.html)).

## Open questions

- Which first users and region: a market garden, an orchard, a university research farm or an extension program? This also sets EU868 or US915. Decided by Amish on 2026-10-02: a US university extension program with a research farm, on US915, with Texas A&M AgriLife Extension as the first candidate to approach (RMS-DEC-001).
- Is one indoor gateway enough for the fields of the first users? With the antenna on the marker rod the link closes at 1 km on paper (RMS-CAL-001), but tall crops such as maize or orchard rows may need an outdoor gateway.
- Do growers want a simple "irrigate now" signal, a depletion chart, or both?
- How often must stakes come out for tillage or harvest, and how quickly must they go back in?
- Is EC (salinity) valued by the first users, or does it add cost for little use in their fields?

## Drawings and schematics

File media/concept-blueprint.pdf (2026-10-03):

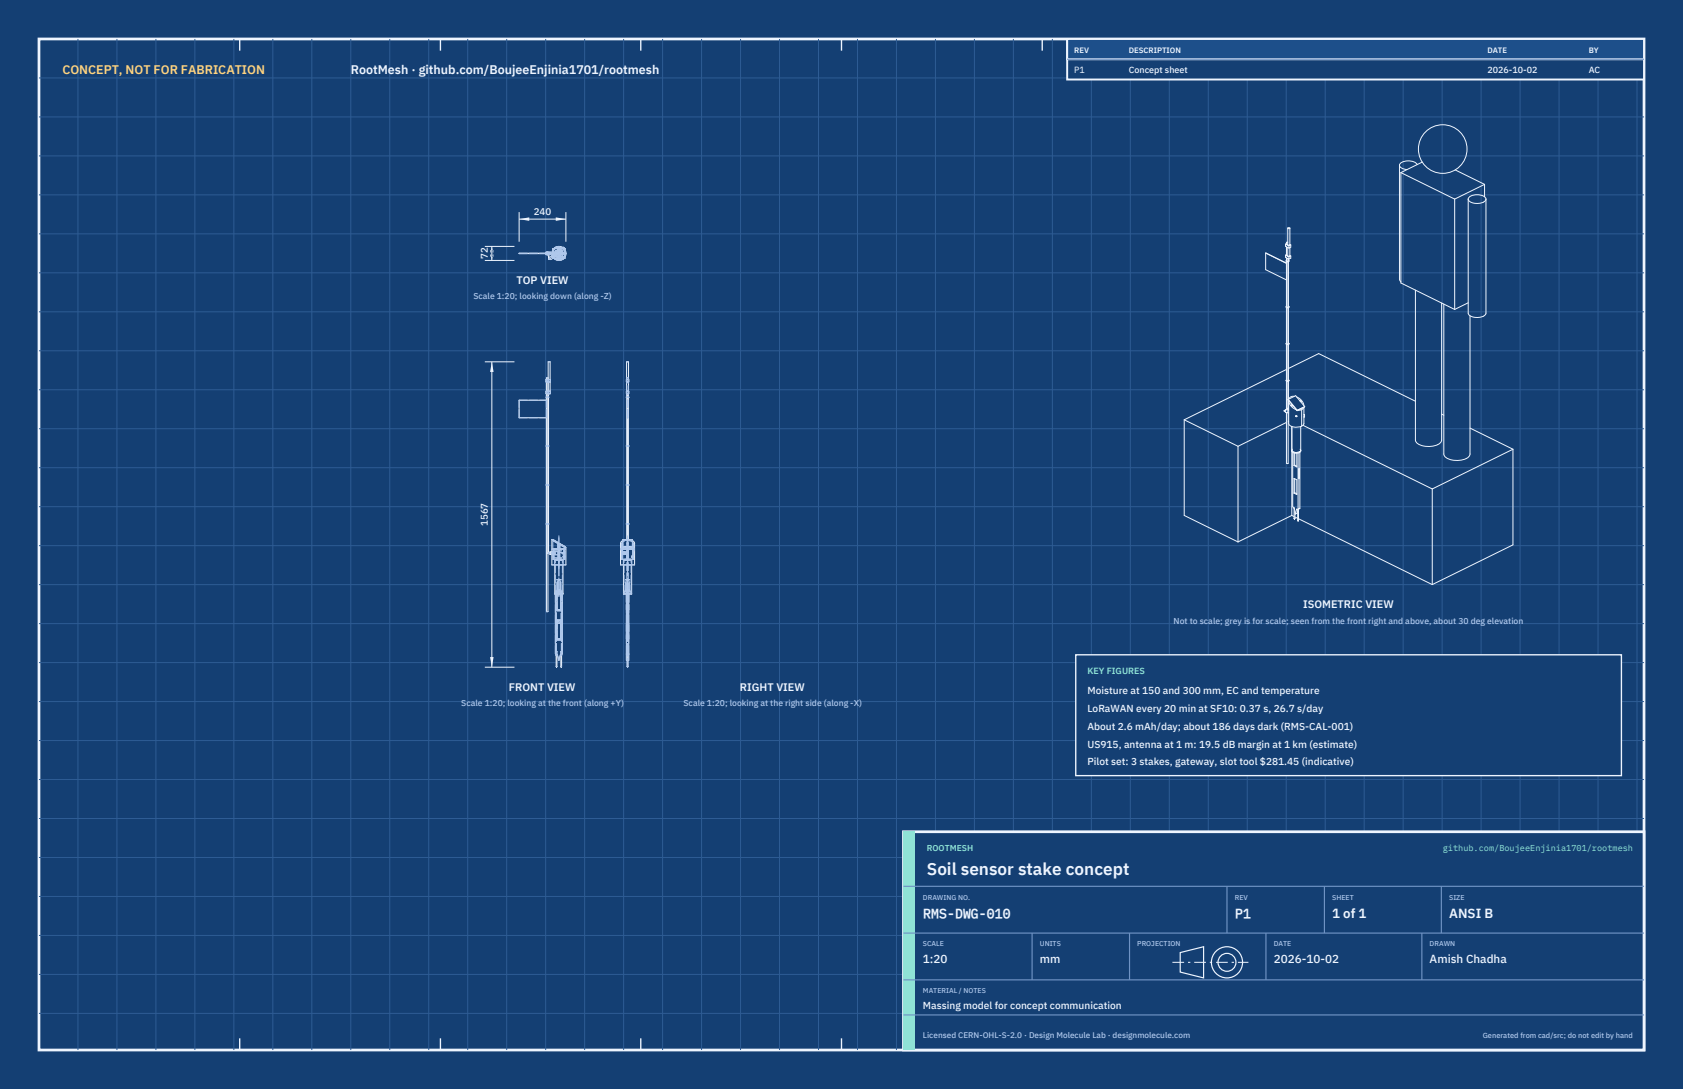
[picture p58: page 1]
CONCEPT, NOT FOR FABRICATION; RootMesh · github.com/BoujeeEnjinia1701/rootmesh; FRONT VIEW; TOP VIEW; RIGHT VIEW; ISOMETRIC VIEW; REV; DESCRIPTION; DATE; Concept sheet; ROOTMESH; github.com/BoujeeEnjinia1701/rootmesh; DRAWING NO. RMS-DWG-010; REV P1; SHEET 1 of 1; SIZE ANSI B; SCALE 1:20; UNITS mm; PROJECTION; DRAWN Amish Chadha; Licensed CERN-OHL-S-2.0 · Design Molecule Lab · designmolecule.com; Generated from cad/src; do not edit by hand

Scale 1:20; looking down (along -Z)

Not to scale; grey is for scale; seen from the front right and above, about 30 deg elevation

KEY FIGURES
Moisture at 150 and 300 mm, EC and temperature
LoRaWAN every 20 min at SF10: 0.37 s, 26.7 s/day
About 2.6 mAh/day; about 186 days dark (RMS-CAL-001)
US915, antenna at 1 m: 19.5 dB margin at 1 km (estimate)
Pilot set: 3 stakes, gateway, slot tool $281.45 (indicative)

Scale 1:20; looking at the front (along +Y)

Scale 1:20; looking at the right side (along -X)

Soil sensor stake concept

MATERIAL / NOTES
Massing model for concept communication

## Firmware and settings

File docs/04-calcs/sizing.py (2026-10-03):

"""RootMesh sizing calculations (RMS-CAL-001 v0.5), TRL 3. US915 and status LED added 2026-10-02.

Run from the repo root:  python docs/04-calcs/sizing.py
Prints every number that RMS-CAL-001 (docs/04-calcs/01-sizing.md) quotes, tagged [A1], [B3] and
so on, and the results table against RMS-REQ-001 v0.4. Geometry comes from cad/src/model.py
(PARAMS and derived), cost from bom/bom.csv and the budget from project.yaml.
All values are first-principles estimates for a paper proof of concept.
"""
import csv
import math
import sys
from pathlib import Path

ROOT = Path(__file__).resolve().parents[2]
sys.path.insert(0, str(ROOT / "cad" / "src"))
from model import PARAMS as P, derived  # noqa: E402

D = derived(P)
RESULTS = []


def out(tag, text):
    print(f"[{tag}] {text}")


def req(rid, value, target, status):
    RESULTS.append((rid, value, target, status))


# ---------------------------------------------------------------- A. Airtime (R4)
PAYLOAD_APP = 11          # bytes: 2 moisture counts, EC, temperature, cell voltage, status
OVERHEAD = 13             # MHDR 1 + FHDR 7 + FPort 1 + MIC 4
PHY = PAYLOAD_APP + OVERHEAD
BW, CR, NPRE = 125e3, 1, 8
FUP = 30.0                # s per node per day, The Things Network fair use
INTERVAL = 20.0           # min, default (RMS-DDR-001 D9)


def toa(sf, n=PHY, bw=BW):
    """Semtech SX127x/SX126x time on air, explicit header, CRC on."""
    ts = 2 ** sf / bw
    de = 1 if (sf >= 11 and bw == 125e3) else 0
    npay = 8 + max(math.ceil((8 * n - 4 * sf + 28 + 16) / (4 * (sf - 2 * de))) * (CR + 4), 0)
    return (NPRE + 4.25) * ts + npay * ts


print("A. Airtime")
out("A1", f"PHY payload {PHY} bytes ({PAYLOAD_APP} application + {OVERHEAD} LoRaWAN overhead); "
          f"US915 DR0 (SF10) allows 11 application bytes, so the payload fits at SF10 in both plans")
per_day = 24 * 60 / INTERVAL
for sf in (7, 8, 9, 10, 11, 12):
    t = toa(sf)
    min_int = t * 24 * 60 / FUP
    out(f"A2-SF{sf}", f"SF{sf}: time on air {t * 1000:.0f} ms; {per_day:.0f} uplinks at {INTERVAL:.0f} min = {t * per_day:.1f} s/day; "
                      f"at 15 min {t * 96:.1f} s/day; shortest interval within {FUP:.0f} s/day = {min_int:.1f} min")
t10 = toa(10)
DWELL = 0.400   # s, US915 maximum dwell time per channel (FCC Part 15.247 hopping rules, LoRaWAN US915)
out("A3", f"US915 dwell limit: SF10 at 125 kHz takes {t10 * 1000:.0f} ms, under the {DWELL * 1000:.0f} ms limit per channel "
          f"({DWELL - t10:.3f} s to spare); SF11 and SF12 at 125 kHz ({toa(11) * 1000:.0f} and {toa(12) * 1000:.0f} ms) are not allowed, "
          f"so DR0 (SF10) is the slowest rate; there is no duty-cycle limit, only fair use")
assert t10 < DWELL
air10 = t10 * per_day
req("R4", f"{air10:.1f} s/day at SF10, 20 min; 15 min needs SF9 or faster ({toa(9) * 96:.1f} s/day)",
    "20 min default; 30 s/day or less at SF10; 10 to 60 min where the SF allows", "Met")
req_note = f"US915 dwell {t10 * 1000:.0f} ms against 400 ms"

# ---------------------------------------------------------------- B. Energy (R6, R7)
print("\nB. Energy")
# Currents from the Wio-E5 module page (Seeed Studio wiki): TX 111 mA at +22 dBm, RX 6.7 mA, sleep 2.1 uA.
I_TX, T_TX = 120.0, t10          # mA, s: 111 mA datasheet at +22 dBm, plus carrier board, rounded up
I_RX, T_RX = 6.7, 0.2            # two receive windows, about 0.1 s each at SF10 preamble detection
I_SENS, T_SENS = 12.0, 1.0       # two TLC555 probes, DS18B20, dividers
I_MCU, T_MCU = 4.0, 1.5          # STM32WL core active
I_EC, T_EC = 10.0, 0.02          # EC burst, 5 kHz square wave through about 330 ohm
V_SUP, V_LED = 3.3, 2.1          # V: supply, green LED forward voltage
R_LED = 560.0                    # ohm, series resistor (BOM 17)
I_LED = (V_SUP - V_LED) / R_LED * 1000   # mA when lit
T_LED, FLASHES, WAKES = 0.1, 3, 5        # s per flash; flashes per wake; magnet or button wakes per day (assumed)
I_SLEEP = 10e-3                  # mA, whole board incl. charger and dividers (module 2.1 uA)
MARGIN = 1.30
CELL_MAH, CELL_V, DOD = 600.0, 3.2, 0.80
SELF_DIS = 0.03                  # per month, LiFePO4 with protection
charge = {"sensors": I_SENS * T_SENS, "mcu": I_MCU * T_MCU, "tx": I_TX * T_TX, "rx": I_RX * T_RX, "ec": I_EC * T_EC, "led": I_LED * T_LED}
q_rep = sum(charge.values())
out("B1", "charge per report " + " + ".join(f"{k} {v:.1f}" for k, v in charge.items()) + f" = {q_rep:.1f} mAs")
out("B1b", f"status LED: {V_SUP:.1f} V, {V_LED:.1f} V forward, {R_LED:.0f} ohm gives {I_LED:.2f} mA; one {T_LED * 1000:.0f} ms blink per uplink = "
           f"{I_LED * T_LED:.2f} mAs; {FLASHES} blinks per wake x {WAKES} wakes per day (assumed) = {I_LED * T_LED * FLASHES * WAKES:.2f} mAs per day")
q_wake = I_LED * T_LED * FLASHES * WAKES                    # mAs per day, magnet or button wakes only
active = (q_rep * per_day + q_wake) / 3600
sleep = I_SLEEP * 24
use = (active + sleep) * MARGIN
selfd = CELL_MAH * SELF_DIS / 30
need = use + selfd
out("B2", f"active {active:.2f} mAh/day + sleep {sleep:.2f} mAh/day = {active + sleep:.2f}; x {MARGIN} margin = {use:.2f} mAh/day "
          f"({use * CELL_V:.1f} mWh/day)")
out("B3", f"self-discharge {selfd:.2f} mAh/day; total daily need {need:.2f} mAh/day")
dark_days = CELL_MAH * DOD / need
out("B4", f"days on the cell alone ({CELL_MAH:.0f} mAh x {DOD:.0%} usable): {dark_days:.0f} days "
          f"({CELL_MAH * DOD / use:.0f} days ignoring self-discharge)")
I_PANEL = 0.5 / 5.0 * 1000       # mA at maximum power point, 1000 W/m2
DERATE = 0.5                     # tilt, dust, heat, linear charger headroom
for psh, shade, label in ((3, 1.0, "3 sun hours, open sky"), (1, 1.0, "1 sun hour, open sky"),
                          (3, 0.1, "3 sun hours, canopy passing 10 %")):
    h = I_PANEL * psh * DERATE * shade
    out(f"B5-{psh}-{int(shade * 100)}", f"harvest {label}: {h:.0f} mAh/day = {h / need:.1f} x daily need")
h1 = I_PANEL * 1 * DERATE
req("R6", f"{h1 / need:.0f} x need at 1 sun hour; {dark_days:.0f} days dark",
    "Energy-neutral at 1 sun hour; 90 days or more dark", "Met")
wh = CELL_MAH * CELL_V / 1000
out("B6", f"cell energy {wh:.2f} Wh (limit 2 Wh); charger NTC window 0 to 45 C; PTC fuse")
req("R7", f"LiFePO4, {wh:.2f} Wh, NTC 0 to 45 C, PTC fuse", "LiFePO4, 2 Wh or less, charge 0 to 45 C, fused", "Met")
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

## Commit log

2026-09-24 Initial scaffold: standard open hardware layout, CERN-OHL-S v2 + MIT licenses
    Claude-Session: https://claude.ai/code/session_01XuhhSU4W6fYhgCfURbrkut
    [bom.csv]
2026-09-25 Adopt portfolio kit v1.3.0: session commands, scale figure, 3D viewer, flow diagrams
    Adds .claude/commands (/populate, /advance-trl3, /rein-in, /refresh-media)
    so every Claude Code session starts from the standard prompts, and extends
    concept media with a 1.75 m scale figure, an interactive glTF viewer and
    system or energy flow diagrams. TRL cap 3 unchanged.
    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
2026-09-25 Kit v1.3.1: renderer fixes from the TremorTrace pilot
    Context scale parts for small objects, cutaway exclusions, and text
    labels in flow diagrams.
    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
2026-09-25 Populate rootmesh to a strong TRL 2 with concept media (batch 6)
    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
    [bom.csv]
2026-09-25 Advance rootmesh to TRL 3 (batches 5 and 6)
    Decisions approved by Amish 2026-09-25 recorded in DDR-001. TRL 4 is on hold.
    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
    [bom.csv, head-enclosure.step, head-enclosure.stl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]
2026-09-26 Accept all recommendations (DDR-002), switch footer to designmolecule.com, add README write-up with new inspiration point
    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
    [bom.csv, head-enclosure.step, rootmesh-stake-assembly.step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]
2026-09-27 Product appearance model and photoreal renders
    Adds cad/src/product_model.py (appearance model for renders only, all main
    dimensions from model.py) and Blender renders in media/render-*.png,
    captioned with the project, repository and viewing direction. README leads
    with the product render; trl stays 3.
    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
2026-10-01 Image quality pass: legible exploded views, flow diagrams and drawing sheets
    Kit 1.6.1 image layout: the parts list sits in its own column, number bubbles sit on visible parts and never overlap, small parts get a leader, pictures are cropped to the subject, flow labels keep numbers with their units, and sheet captions and the revision table no longer overprint. Concept images, blueprint and general arrangement sheet regenerated; repo-specific labels moved clear of other text and lines.
2026-10-01 Kit 1.7.0: constructable design, illustrated build plan and design decisions register
    The design is now constructable: every part can be made and fits its neighbours, with each change recorded in a Design for construction decision record (made under Amish's 2026-09-30 instruction; ope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
    FlexHand also credits Dr. Geeti Chadha as a contribut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
    [antenna-clip.step, antenna-clip.stl, bom.csv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]
2026-10-02 Record Amish's approval of the open-decision recommendations
    Amish approved the recommendation on every open decision in the design decisions register ("i approve your recommendations for all 555 open decisions.", 2026-10-02). Each decision is moved to Decisio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
2026-10-03 Carry approved follow-ups into the design and redo photoreal renders
    Amish approved the follow-up actions from the open-decision sign-off ("APPROVED CHANGES, COMPLETE THESE", 2026-10-02), the design-for-construction change tables in ten repos, the last wave's open dec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
    [antenna-clip.step, bom.csv, cell-holder.step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]

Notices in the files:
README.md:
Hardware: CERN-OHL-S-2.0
